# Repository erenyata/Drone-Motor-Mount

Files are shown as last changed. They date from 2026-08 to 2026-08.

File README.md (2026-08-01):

# Drone-Motor-Mount
I've developed a sandwich-style clamp motor mount for general purpose 7" quadcopter(x) drone. I created a document for each process of design to explain what I've done. You can view those files in repository. 

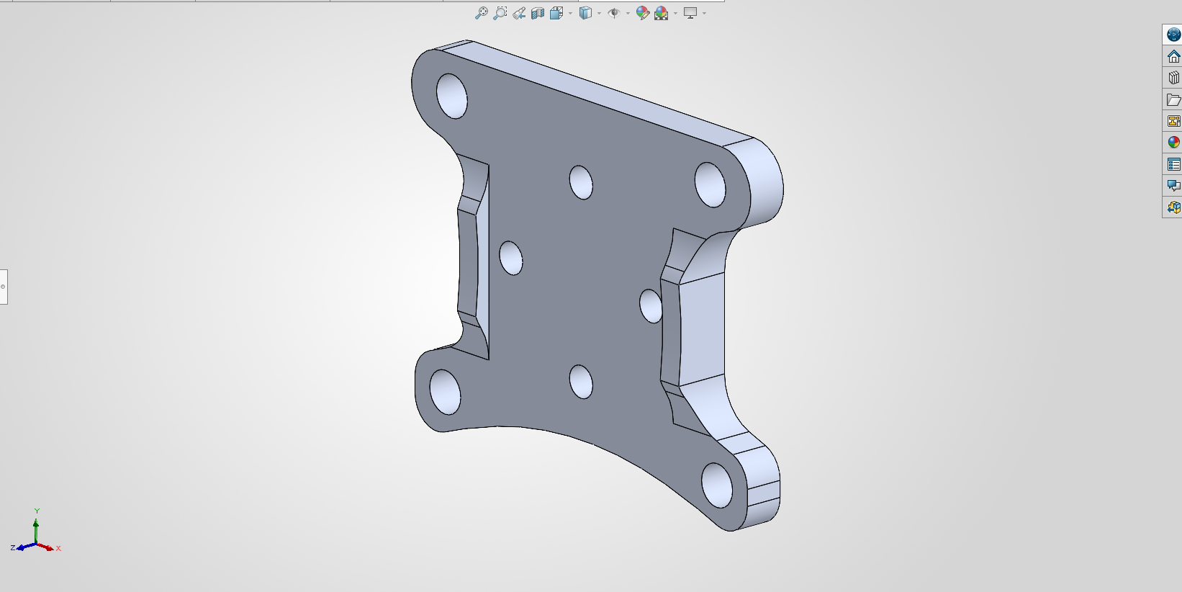
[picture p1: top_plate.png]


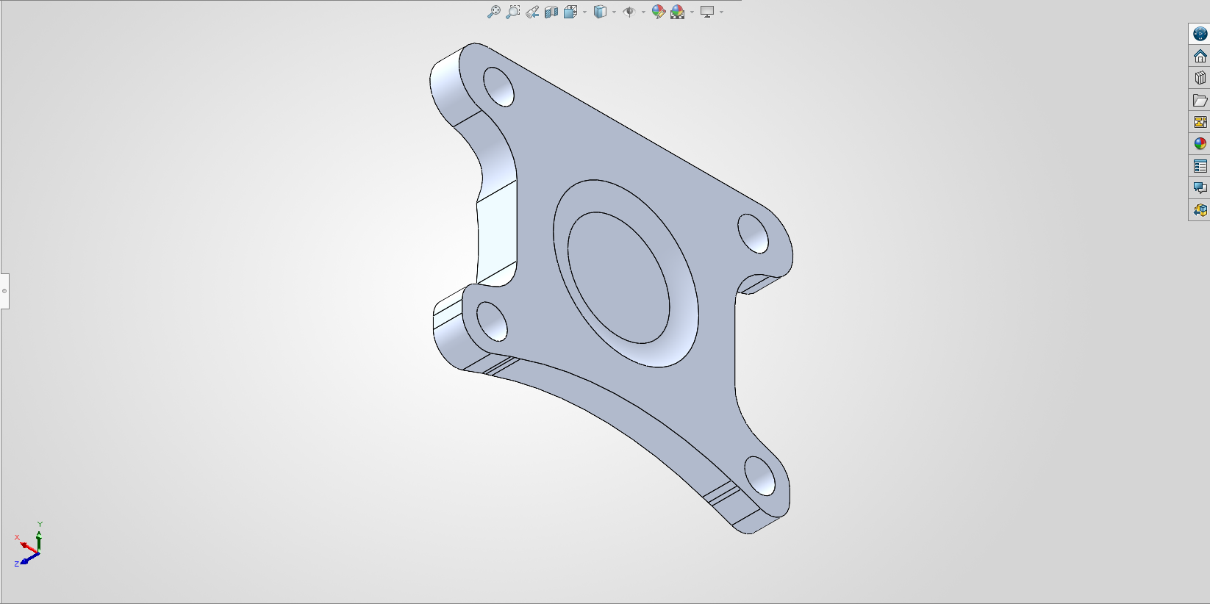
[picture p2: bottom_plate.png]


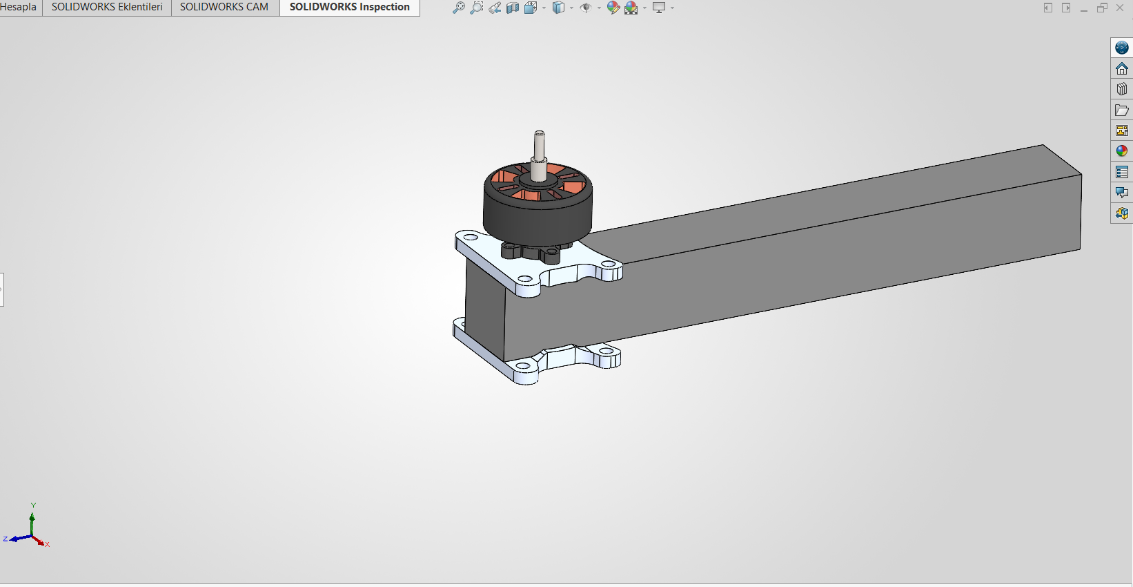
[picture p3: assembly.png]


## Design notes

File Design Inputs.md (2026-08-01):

# Design Inputs

Selected Motor:
iFlight XING-E Pro 2809

Reason:
Selected as the design input based on the benchmark study.

This motor is considered fixed throughout the project.
Motor selection is outside the scope of this project.

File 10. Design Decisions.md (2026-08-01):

# Design Decisions

| Observation | Estimated Reason | Confidence Level |
|---|---|---|
| Fillets used | To reduce stress concentration | 90% |
| 4 bolts | To better handle vibration and moment | 60% |
| Clamp connection | To avoid drilling the carbon fiber and ease of maintenance | 50% |
| Motor aligned with the arm axis | The motor generates torque, thus forcing the attached arm to rotate around its own axis. If it is not on the arm axis, being to the right or left can cause damage to the arms. Being above or below can create the same effect. M = F × e. Here, e is the eccentricity. If the motor moves away from the axis, an additional bending moment is generated on the arm. Therefore, not only the motor torque but also the moment created by the thrust affects the design. | 60% |
| Pocketing (pocket milling) | To reduce weight | 50% |
| Small geometry | To reduce weight | 50% |

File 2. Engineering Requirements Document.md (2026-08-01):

# Engineering Requirements Document

## 1. Functional Requirements
FR-001: The motor mount shall ensure the secure attachment of the motor to the aircraft.
FR-002: The motor mount shall maintain the position of the motor under design loads and prevent unwanted displacements.

## 2. Interface Requirements
IR-001: The motor mount shall be compatible with a 25x25 mm carbon fiber arm.
IR-002: The motor mount shall be compatible with the mounting geometry of the selected motor.

## 3. Performance Requirements
PR-001: The motor mount shall maintain its structural integrity under the defined design loads.
PR-002: The mass of the motor mount shall not exceed TBD grams.
 
## 4. Manufacturing Requirements
MR-001: The motor mount shall be manufacturable using a 3-axis CNC milling process.

## 5. Verification Requirements
VR-001: All critical dimensions shall be verified via the CAD model.
VR-002: Structural strength shall be verified through Finite Element Analysis (FEA).
VR-003: The part mass shall be verified by calculation via the CAD model.

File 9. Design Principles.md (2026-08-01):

# Design Principles

| No | Design Principle | Basis |
|---|---|---|
| DP-001 | The motor should be aligned with the arm axis as much as possible. | To reduce the bending moment |
| DP-002 | Sharp internal corners should be avoided. | Stress concentration |
| DP-003 | Unnecessary material usage should be avoided. | Weight optimization |
| DP-004 | Drilling the carbon fiber arm should be avoided as much as possible. | Benchmark observations |
| DP-005 | The motor mount must provide sufficient rigidity. | Benchmark |

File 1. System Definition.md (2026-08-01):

System Name: Undefined UAV

Mission: An unmanned aerial vehicle developed to provide reconnaissance, surveillance, and rapid situational awareness.

Configuration: Quadcopter (X Configuration)

Number of Motors: 4

Propeller Size: 7 inch
 
Target Flight Time: 20-30 minutes

Maximum Takeoff Weight (MTOW): ~ 2-2.5 kg

Payload: ~ 0.5–0.8 kg (Camera, sensors, or testing equipment)

Operating Environment: Outdoor

Primary Design Objective: A CNC-machinable motor mount designed to securely attach to a 25x25 mm carbon fiber arm, engineered to provide maximum structural rigidity while keeping the weight to an absolute minimum.

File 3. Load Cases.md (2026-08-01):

# Load Cases

## LC-001 Hover
The drone is hovering at a constant altitude (steady hover).
The motors produce sufficient thrust to balance the weight.

## LC-002 Maximum Thrust
The motor produces maximum continuous thrust.
This represents one of the highest axial loads on the motor mount.

## LC-003 Maximum Torque
The motor produces maximum torque.
The reaction torque generated on the motor body must be counteracted by the motor mount.

## LC-004 3g Maneuver
The drone performs an aggressive maneuver at approximately 3g.
Inertial forces resulting from the motor mass impose additional loads on the motor mount.

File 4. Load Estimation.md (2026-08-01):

## LC-002 Maximum Thrust

Physical Meaning:
The condition where the motor produces maximum continuous static thrust.
This load represents the primary axial load in the motor mount design.

Applied Force:
T = 28.77 N

Motor Weight:
W = 0.592524 N

Resulting Load on Mount:
R = 28.18 N

Factor of Safety
FoS = 2

Design Load:
R = 56,36 N

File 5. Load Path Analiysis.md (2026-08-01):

# Load Path Analysis

## LC-002 Maximum Thrust

### Load Source

The propeller generates thrust.

↓

### Transmission

The thrust force is transmitted to the motor mount through the following path:

Propeller

↓

Motor Shaft

↓

Motor Housing

↓

Mounting Bolts

↓

Motor Mount

↓

Carbon Fiber Arm

↓

Drone Frame

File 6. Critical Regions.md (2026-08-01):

# Critical Regions

CR-001: Motor mounting holes
Reason: Primary load transfer region.

CR-002: Transition between motor plate and arm clamp
Reason: Bending moment and stress concentration.

CR-003: Internal fillets
Reason: Stress concentration reduction.

CR-004: Arm clamping interface
Reason: Load transfer to carbon fiber arm.

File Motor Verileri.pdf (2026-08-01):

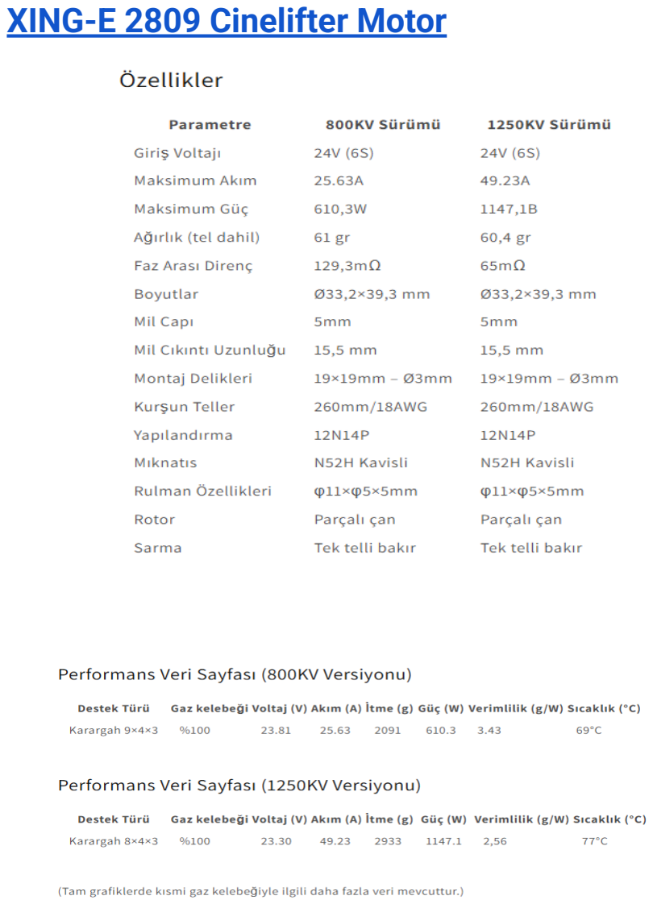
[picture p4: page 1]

XING-E 2809 Cinelifter Motor (https://rcdrone.top/tr/products/iflight-xing-e-2809-800kv-1250kv-brushless-cinelifter-motor-for-6s-7-8-inch-fpv-drones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)

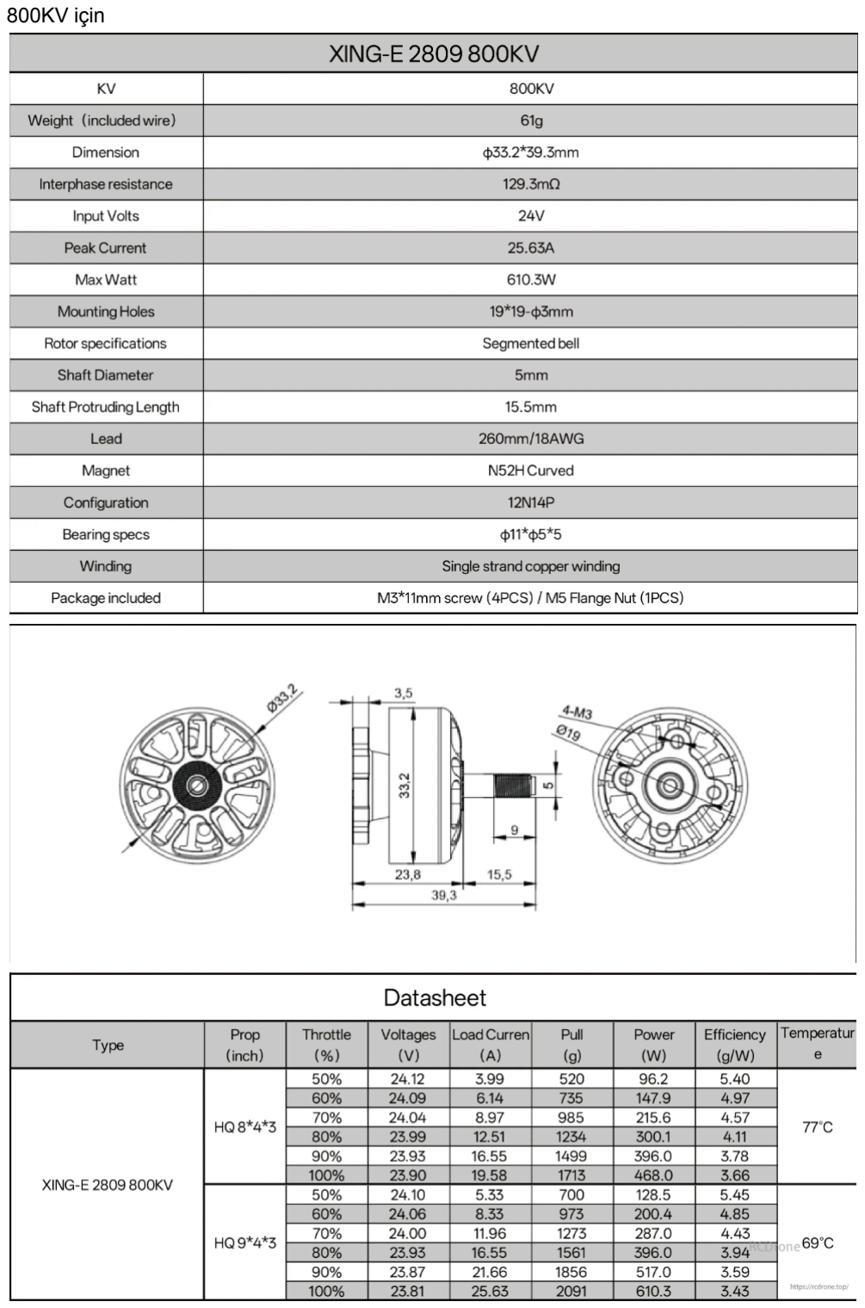
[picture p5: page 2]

800KV için

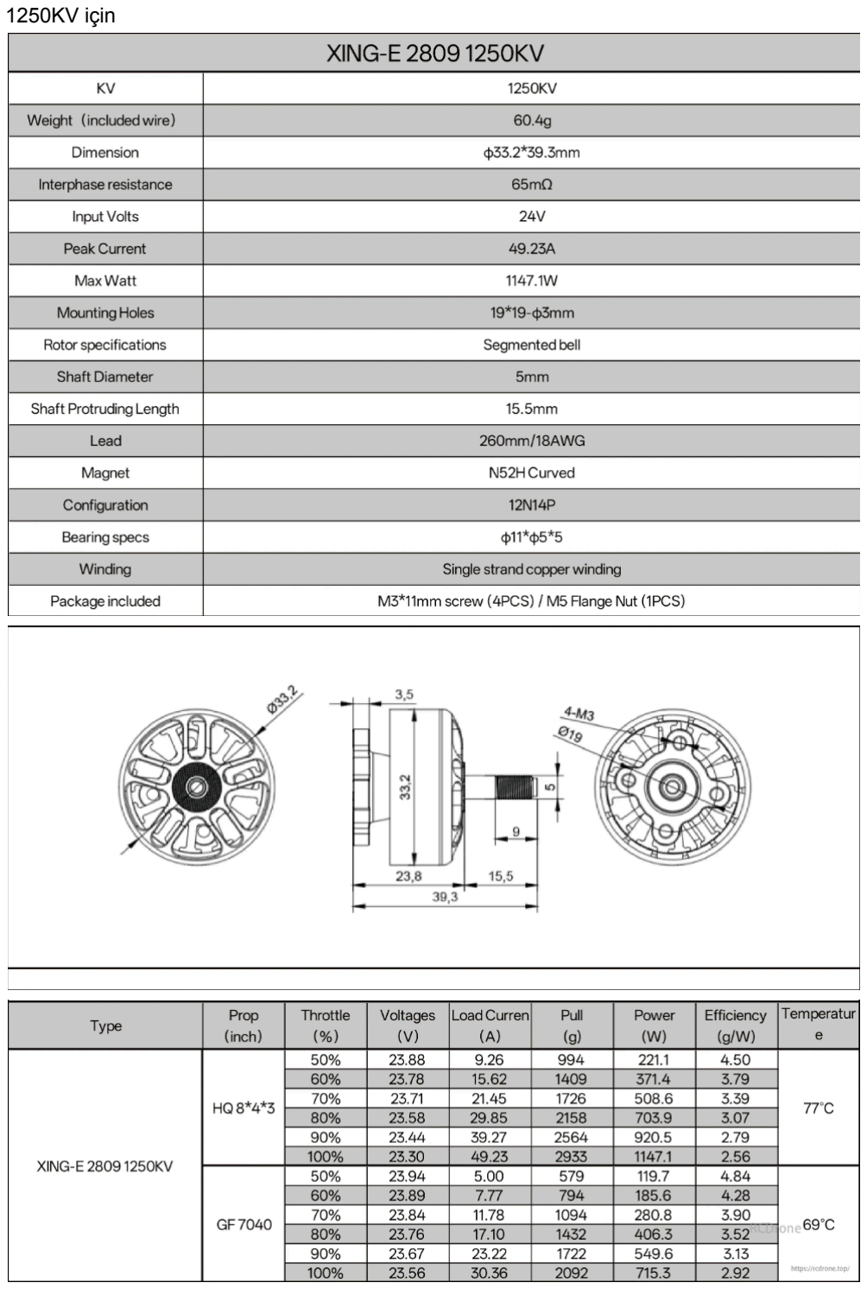
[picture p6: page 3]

1250KV için

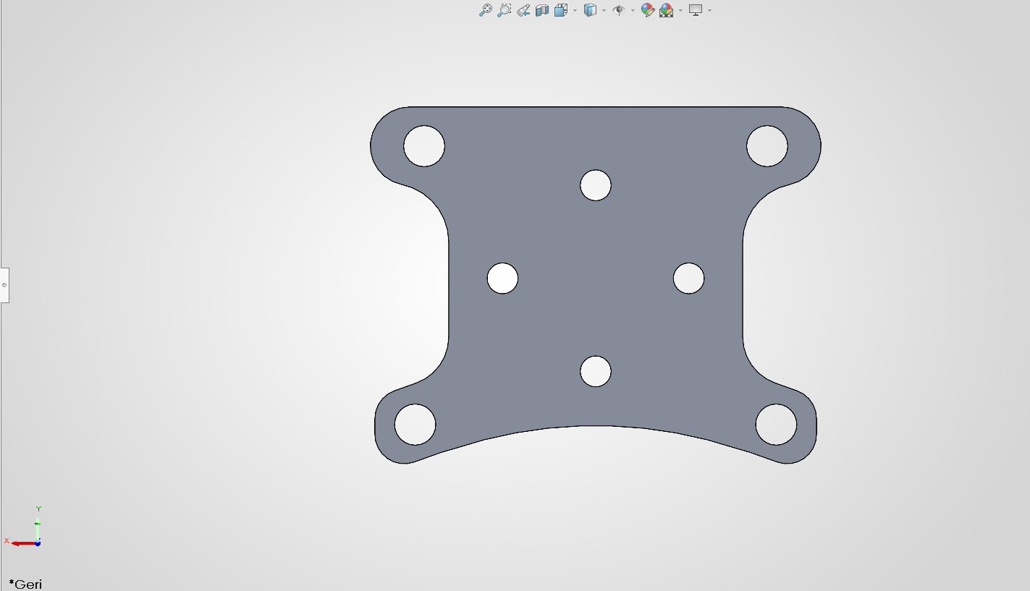
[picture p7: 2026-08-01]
top_plate_2.png

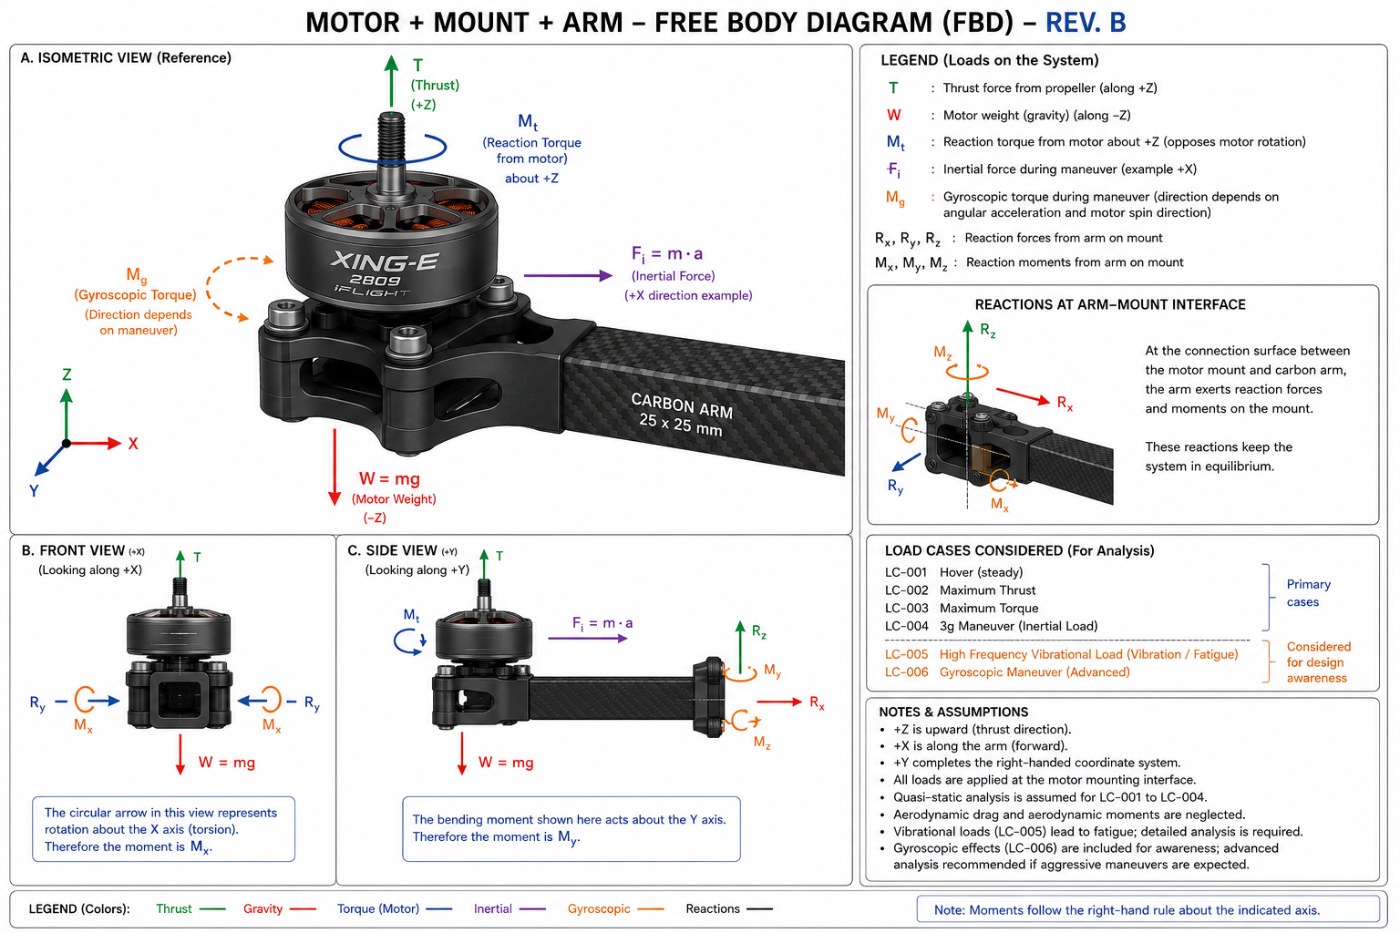
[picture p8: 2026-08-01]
Motor-Mount-Arm FBD.png

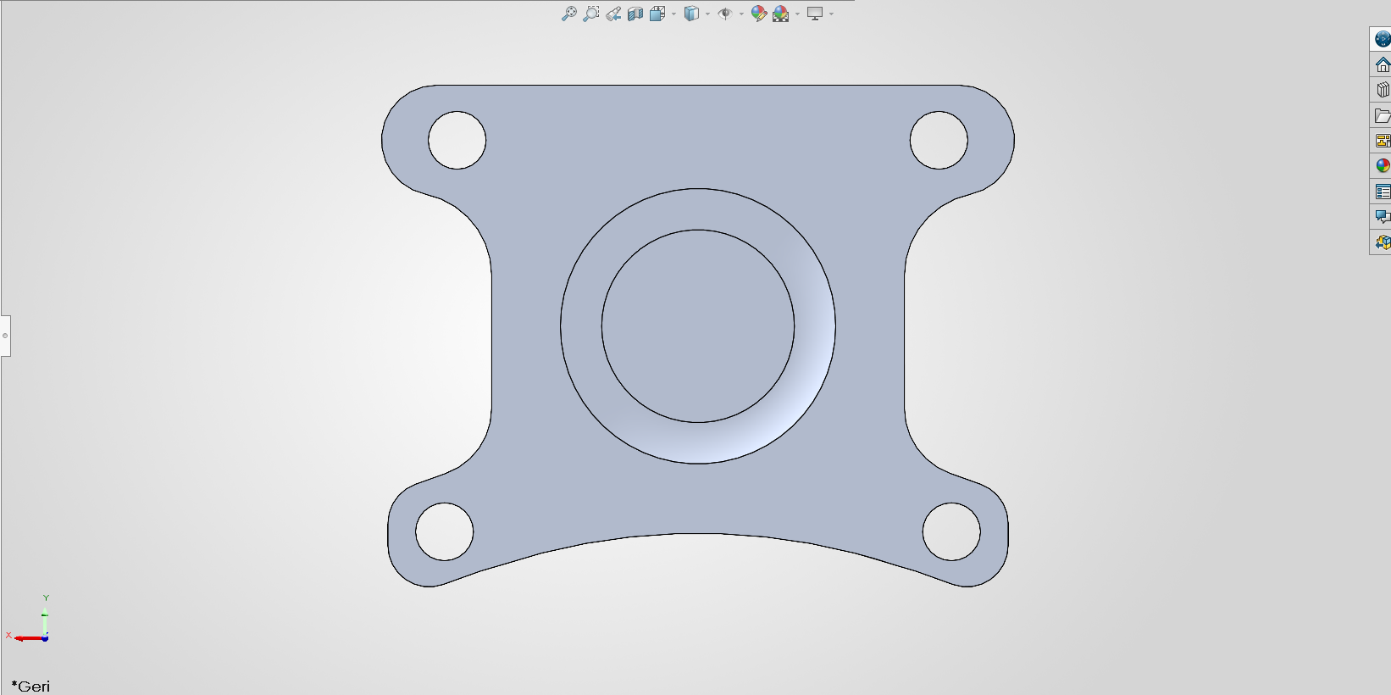
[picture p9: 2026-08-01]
bottom_plate_2.png

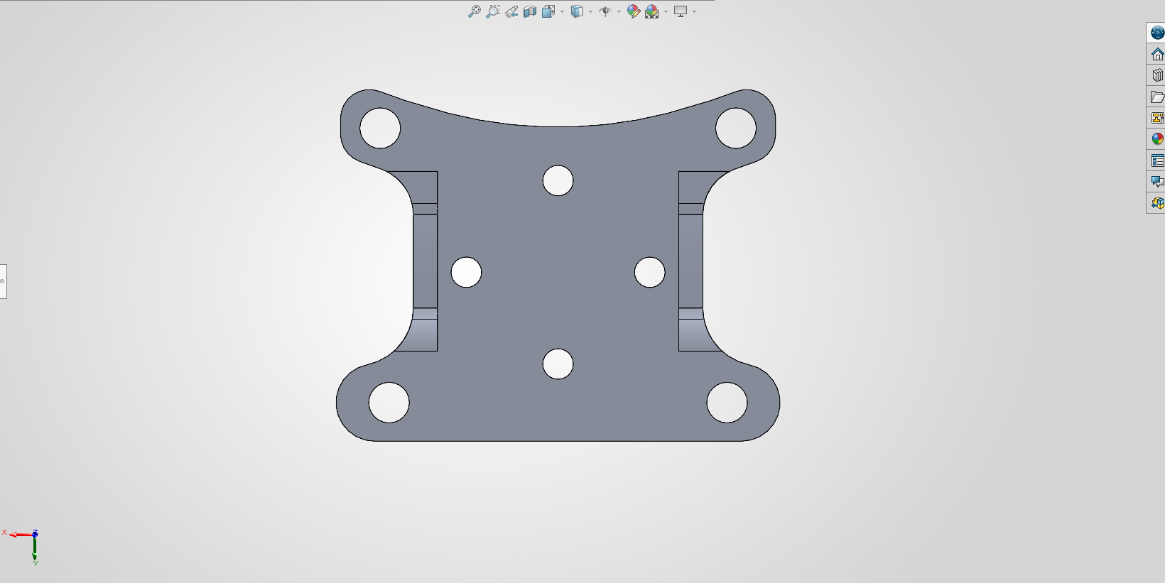
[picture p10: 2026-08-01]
top_plate_3.png

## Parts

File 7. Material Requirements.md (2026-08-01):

# Material Requirements

MR-001: High specific strength
Reason: Weight reduction.

MR-002: High stiffness
Reason: Maintain motor alignment.

MR-003: Good fatigue resistance
Reason: BLDC vibration.

MR-004: Good machinability
Reason: 3-axis CNC manufacturing.

MR-005: Corrosion resistance
Reason: Outdoor operation.

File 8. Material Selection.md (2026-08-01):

# Material Selection

## Candidate Materials

- Aluminum 6061-T6
- Aluminum 7075-T6
- Aluminum 2024-T3
- Ti-6Al-4V
- Carbon Fiber Composite (CFRP)

## Evaluation Criteria

| Criterion | Weight |
|---|---:|
| Specific Strength | 30% |
| Stiffness | 20% |
| Fatigue Resistance | 20% |
| Machinability | 15% |
| Corrosion Resistance | 10% |
| Cost | 5% |

## Material Assesment 

### CFRP
* Anisotropic material.
* Damage can occur around the holes.
* The manufacturing process is more complex.
* Does not fully comply with MR-001 and MR-004.

### Titanyum
* Very expensive.
* Difficult to machine via CNC.
* Our loads are quite low.

#### 2024-T3
* Low corrosion resistance.

### 6061-T6
#### Pros
* Better corrosion resistance
* Lower cost
* Easier machinability

#### Cons
* Lower strength
* Requires larger cross-sections

### 7075-T6
#### Pros
* Higher strength
* Lower weight
* Smaller geometry

#### Eksileri
* Lower corrosion resistance
* Higher cost

The 7075-T6 alloy was selected due to its high specific strength, adequate stiffness, good machinability, and compatibility with benchmark studies. By providing higher strength compared to the 6061-T6 alloy, it will make it possible to achieve a lighter and more compact geometry. Its corrosion resistance against outdoor conditions can be enhanced by applying an anodized coating.

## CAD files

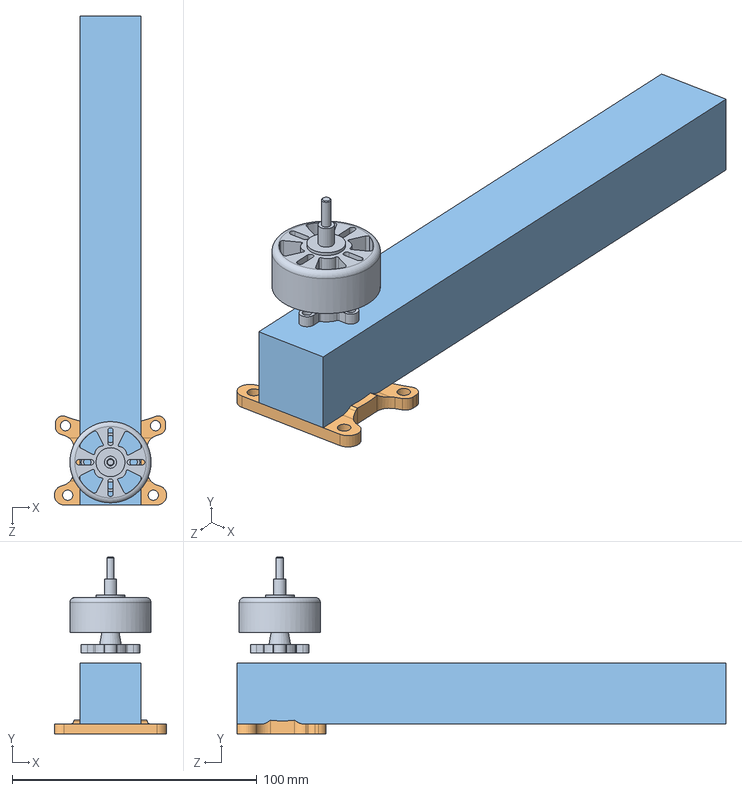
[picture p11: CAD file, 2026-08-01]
assembly.SLDASM
46.0 x 72.3 x 200.0 mm
25x25_carbon_fiber_arm
bottom_plate_alternative_2
xing-e-2809-cinelifter-motor-rough-sketch

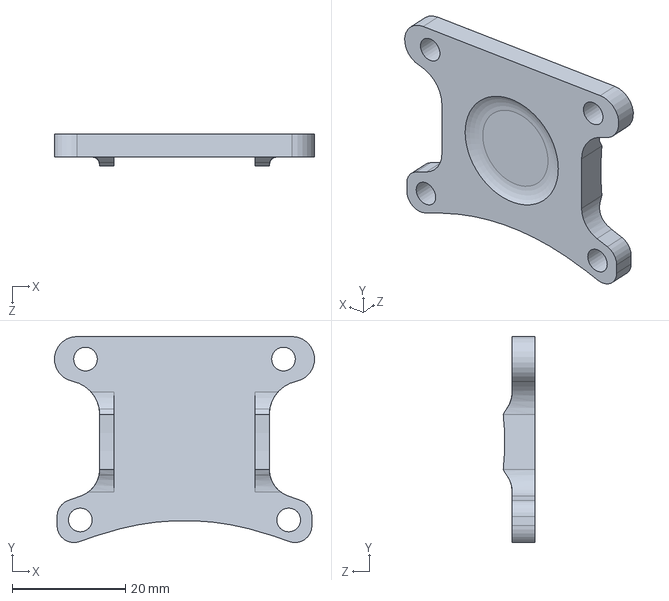
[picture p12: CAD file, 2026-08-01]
bottom_plate_alternative_2.SLDPRT
46.0 x 36.4 x 5.58 mm

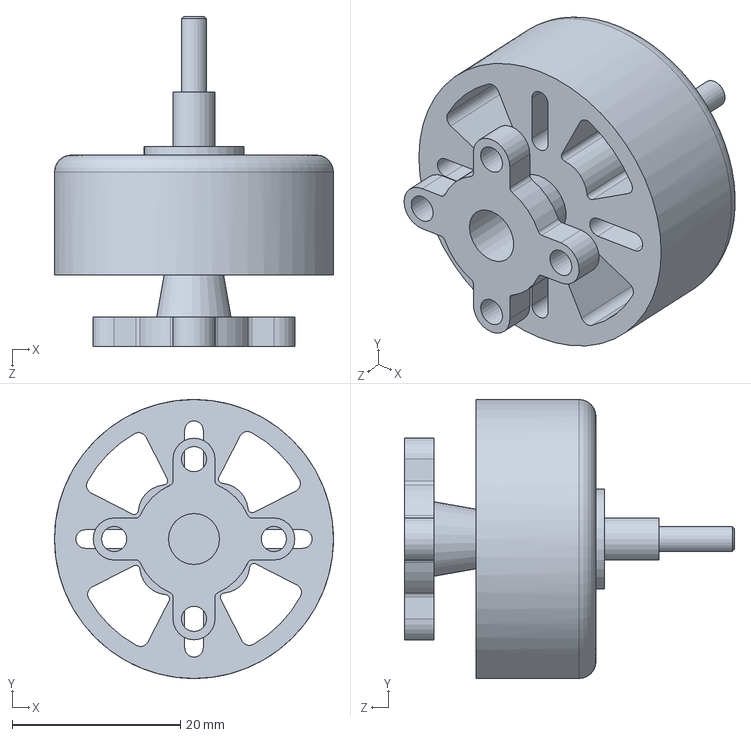
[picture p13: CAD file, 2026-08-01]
xing-e-2809-cinelifter-motor-rough-sketch.SLDPRT
33.2 x 33.2 x 39.3 mm

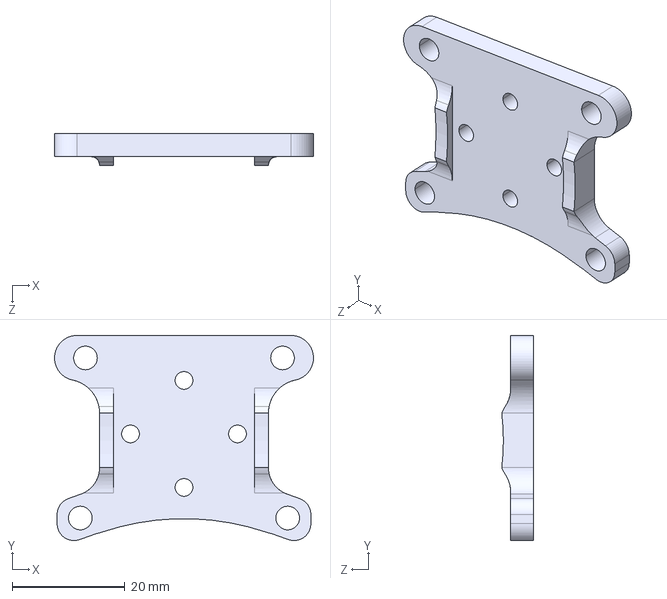
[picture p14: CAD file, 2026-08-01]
top_plate_alternative_2.STEP
46.0 x 36.4 x 5.60 mm

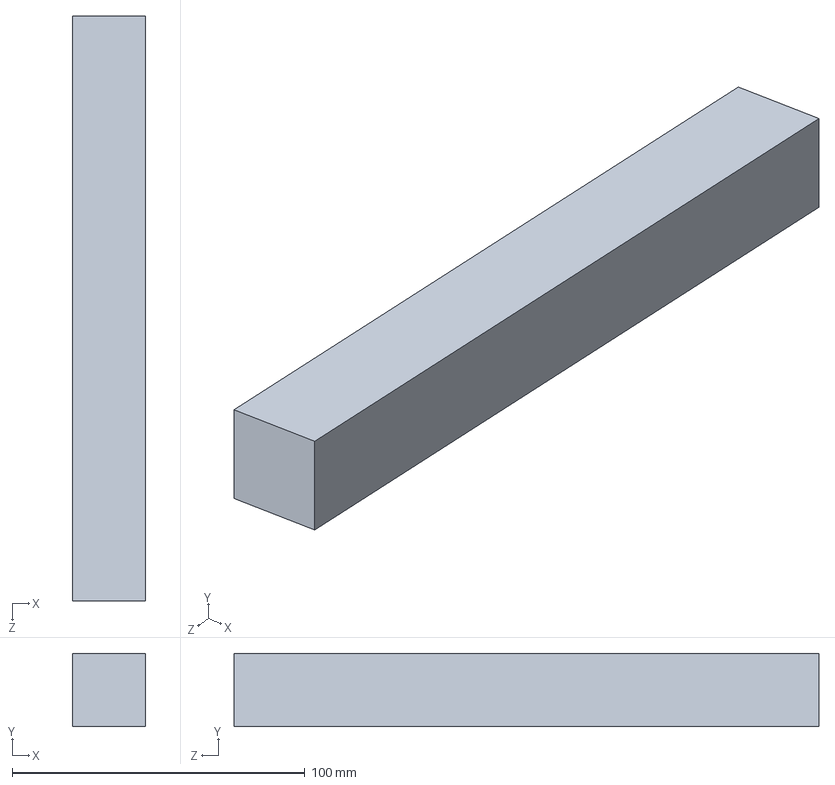
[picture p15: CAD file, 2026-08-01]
25x25_carbon_fiber_arm.SLDPRT
25.0 x 25.0 x 200.0 mm

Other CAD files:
bottom_plate_alternative_2.SLDDRW
top_plate_alternative_2.SLDDRW
top_plate_alternative_2.SLDPRT

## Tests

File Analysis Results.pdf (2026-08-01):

# Analysis Results

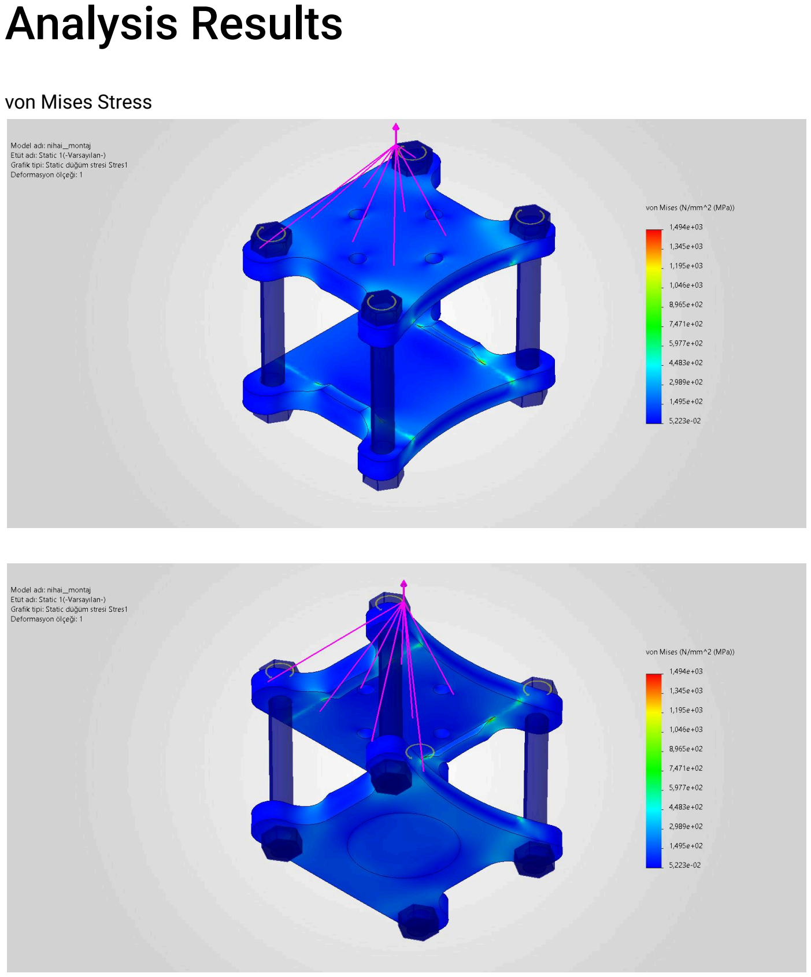
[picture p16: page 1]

von Mises Stress

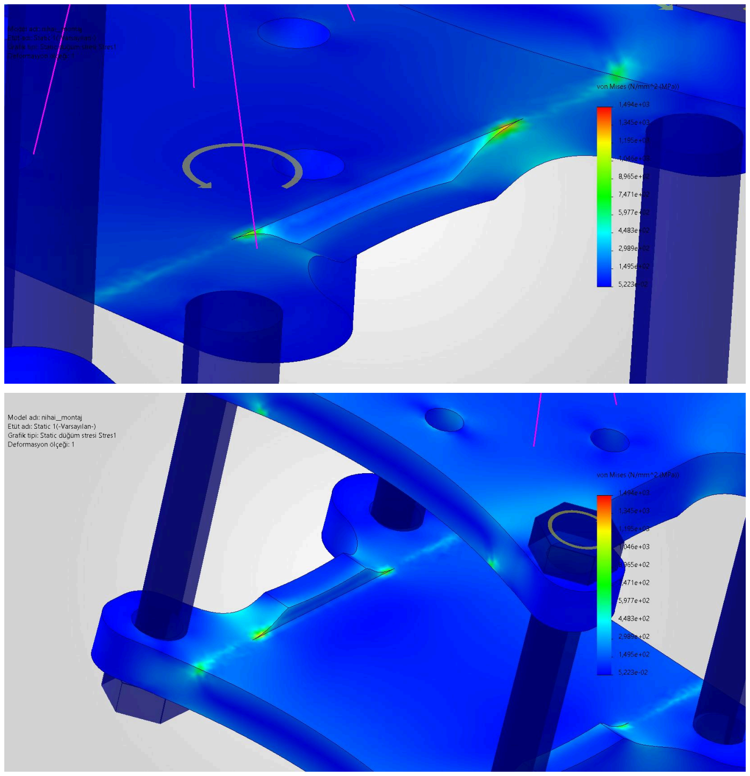
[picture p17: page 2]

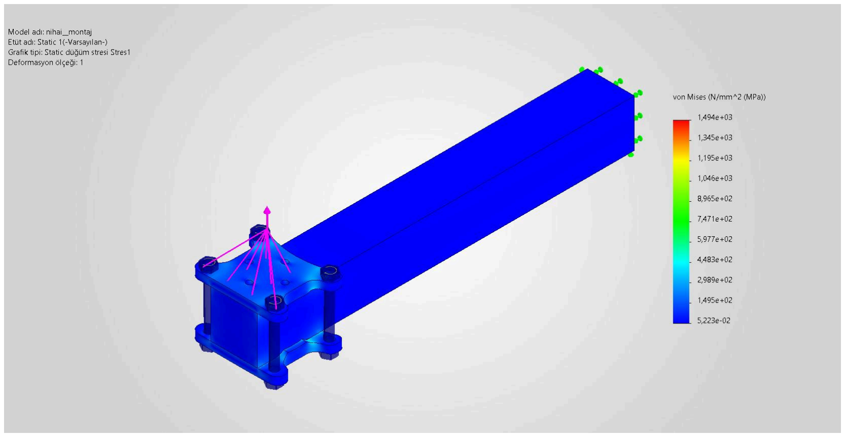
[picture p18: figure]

Total Displacement

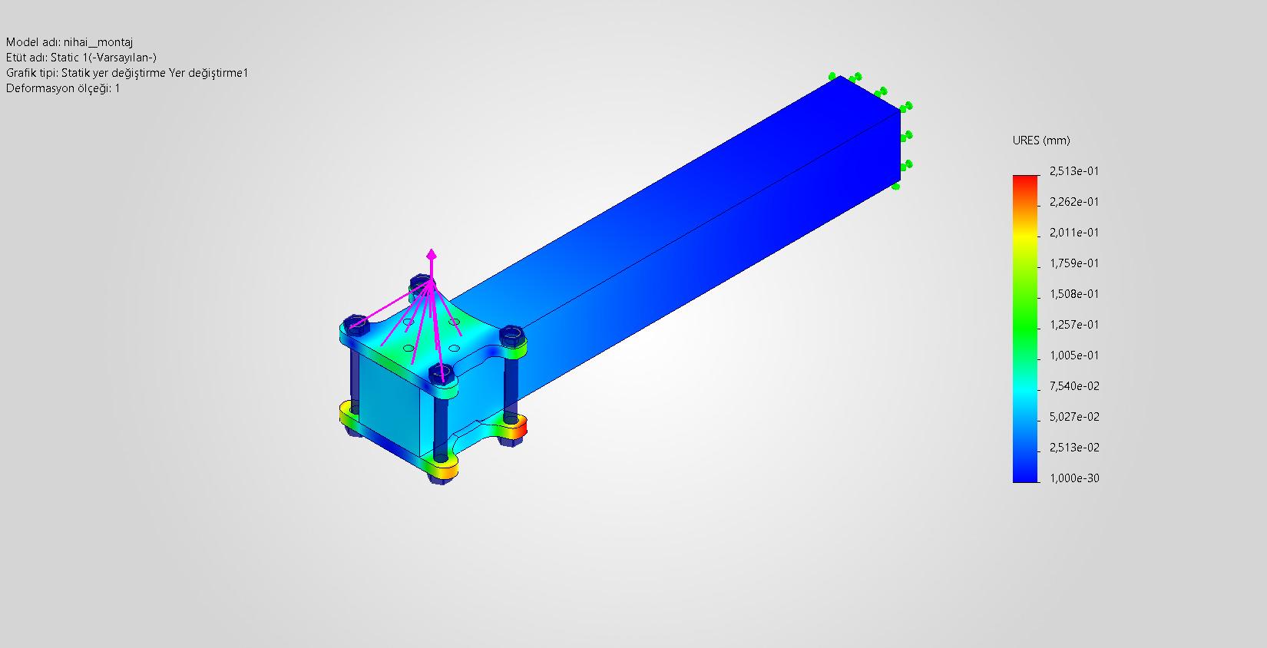
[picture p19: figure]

Analysis and Manufacturing Considerations: The FEA results revealed mathematical stress singularities and localized stress concentrations at the inner corners of the side supports. However, since the part will be manufactured using a three-axis CNC milling process, the natural fillet radius left by the cutting tool (end mill) will smooth these sharp corners and eliminate the unrealistic stress concentration observed in the simulation. Therefore, the design was intentionally retained in its current form and considered ready for manufacturing. Under the maximum thrust load case (LC-002), the maximum resultant displacement (URES) value of 0.25 mm confirms that the motor mount possesses high structural stiffness and provides sufficient structural integrity to prevent vibration-induced stability issues (commonly referred to as the "jello effect") during flight.

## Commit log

2026-08-01 Added CAD Files
    [25x25_carbon_fiber_arm.SLDPRT, assembly.SLDASM, bottom_plate_alternative_2.SLDPRT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]
2026-08-01 Added Technical Drawings
    [bottom_plate_alternative_2.SLDDRW, top_plate_alternative_2.SLDDRW]
2026-08-01 Enhance README with design documentation details
    Added documentation details about the design process for the motor mount.
2026-08-01 Include images of motor mount components in README
    Added images of the top and bottom plates to the README.
2026-08-01 Added assembly photo
2026-08-01 Add assembly image to README
2026-08-01 Update motor mount description in README
2026-08-01 Added "Motor Verileri.pdf" file
    Projede referans olarak kullandığım XING-E 2809 Cinelifter Motor'un verileri. Proje 1250KV modeli referans alınarak yapılmıştır.
